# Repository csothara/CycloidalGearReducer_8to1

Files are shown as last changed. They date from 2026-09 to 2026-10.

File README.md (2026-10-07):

# CycloidalGearReducer_8to1
PID_noload2
result1
crosssection_analysis1

A personal project consisting in developing a cycloidal 8 to 1 reducer compatible with a NEMA17 stepper motor with a D-shaft.
This follows directly my previous project of a robotic arm articulated by servo motors after noting the flaws, design and servos limitations (extreme lateral play and backlash, bad repeatability etc).

Steppers can't generate a high torque, at least not in this context of building a robotic arm, so I need some gear reduction system to multiply the initial torque of 0.4Nm while being compact, having no backlash, high precision and being shock resistant.
I therefore chose the cycloidal type of reducers with a 8 to 1 reduction ratio, which, if well-designed enough, satisfies all my requirements and would give a torque of 3.2Nm (probably less because of friction...).
I also have to track the orientation of the output shaft with a magnetic encoder (AS5600) and communicate this angle to a PID closed loop control. 

In this project, I learned how to use Autodesk Fusion CAD because I don't want to use Blender (which I used to build the servo robot arm)

crosssection_analysis1

crosssection_analysis2

encoder

green is the input, blue is the stator, yellow is the gears, red is the output shaft, white rectangle is the magnet, solid dark green hanging is the encoder

Sources of materials that helped me a lot:
www.youtube.com/watch?v=dv2URKU5YNU //most useful video for me for understanding cycloidal reducers
www.youtube.com/watch?v=stGwlJ-GMCY
youtu.be/OsS9-FzKN6s?si=D96ZwXOTy2uzee3U
www.youtube.com/watch?v=VbAhkESCRFM //what taught me almost everything i needed for using Fusion CAD
youtu.be/jQ6LQBFZXmU?si=3ZcaHU4sGydaDMxd

Parts list:
26x 693ZZ Bearing                 www.amazon.fr/dp/B0FP4ZW9JP
2x 6702-2RS Bearing               www.amazon.fr/dp/B0GL6KSBSH
2x 6807-2RS                       www.amazon.fr/dp/B09HX12WTC
M3 Screws and Nuts                www.amazon.fr/dp/B0B3MGZ7T2 www.amazon.fr/dp/B0DPWZ53X4
AS5600 Magnetic Encoder           fr.aliexpress.com/item/1005009026945907.html
ESP32-S3 Microcontroller          fr.aliexpress.com/item/1005008845049090.html
TMC2209 V2.0 Stepper Motor Driver fr.aliexpress.com/item/1005010646278731.html
100µF Capacitor
some wires

The most difficult part for me in this project was to think about a step by step assembly process while making it compact and making every parts fit snuggly which led me to do a lot of iterations in certain models, even order an urgent express delivery for new parts, for example I realized very late that I needed much bigger bearings 6807-2RS because I did not think about needing a bigger output shaft with enough space for multiple screws to bear load, this adjustment rendered my gearbox to be too thick for my 20mm M3 screws which led to another express delivery of longer M3 screws, caliper broke etc

My experience of 3D modelling on Blender I gathered from the first lockdown translated really well to Fusion. The parametric curve maths logic of FUsion made it so much easier for me to keep track of all the dimensions otherwise impossible or very frustrating on Blender which uses a polygon mesh logic. This project took me 4 weeks to develop which would have taken months on Blender (the servo robot arm took me over 6 months).

Testing and assembly guide soon

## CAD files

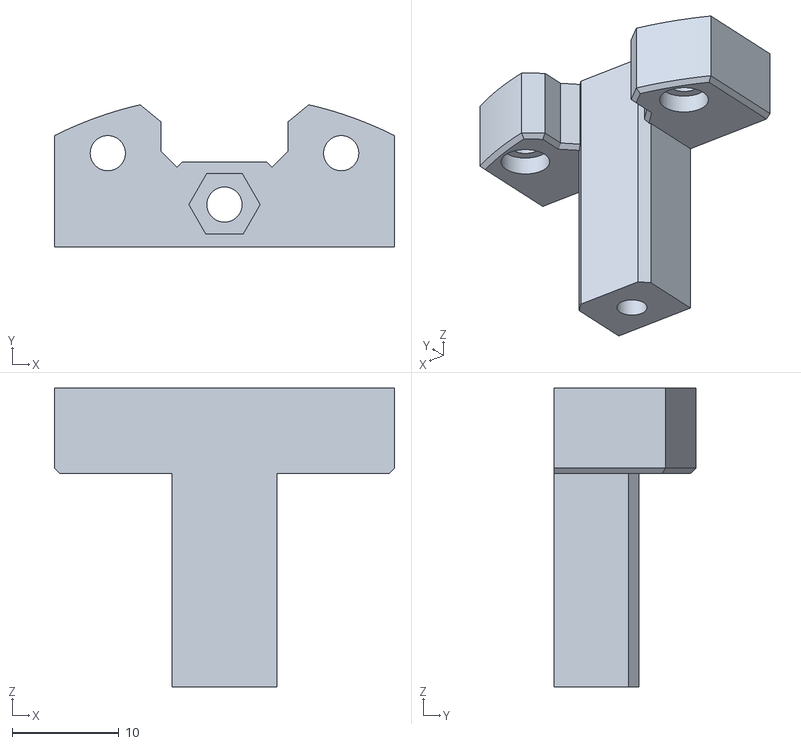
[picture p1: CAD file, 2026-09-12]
STEPPERMOUNT2_test_1.stl
31.9 x 13.4 x 28.0

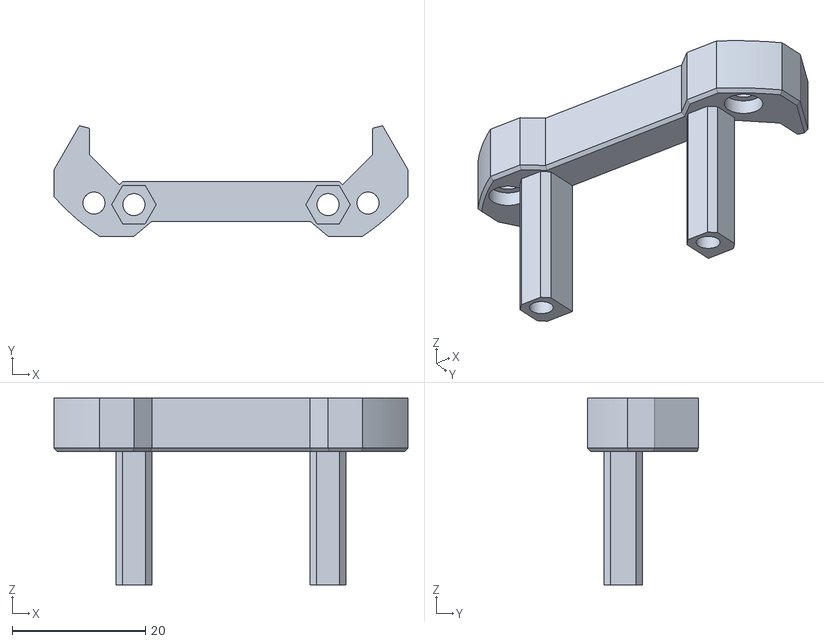
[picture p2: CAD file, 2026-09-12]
STEPPERMOUNT1_test_1.stl
53.1 x 16.6 x 28.0

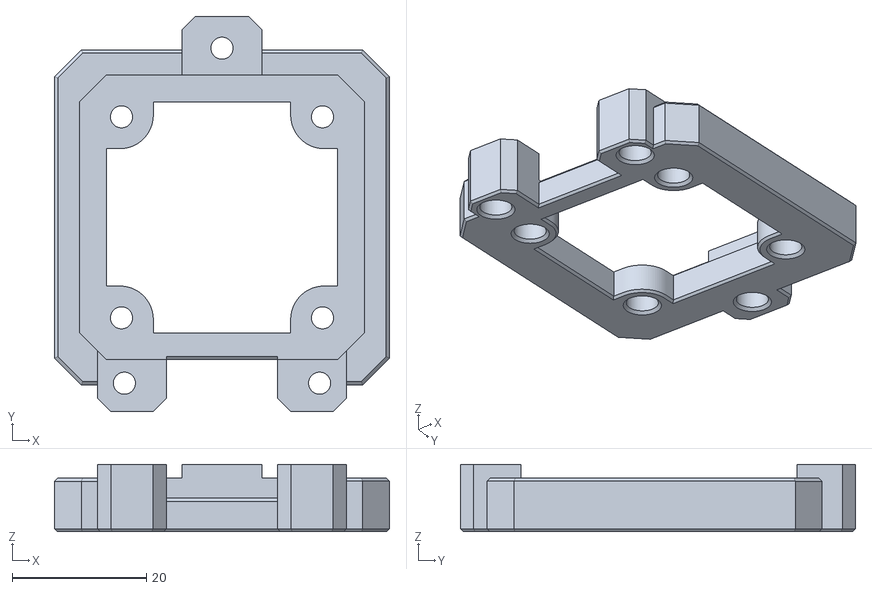
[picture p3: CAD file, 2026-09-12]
STEPPERMOUNT3_test_1.stl
50.0 x 59.0 x 10.0

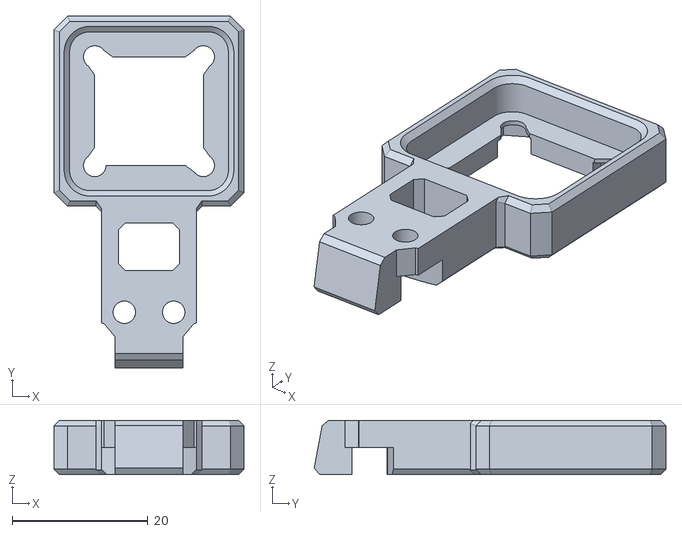
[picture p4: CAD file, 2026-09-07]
ENCODERHOLDER_test_2.stl
28.0 x 51.8 x 8.00

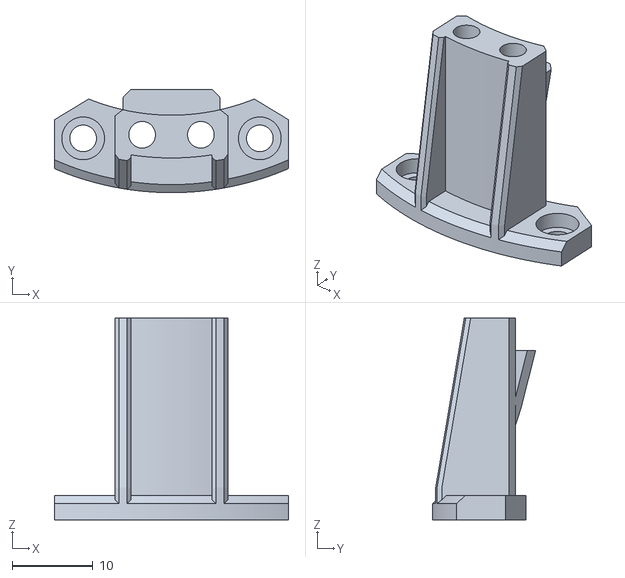
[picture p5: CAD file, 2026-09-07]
ENCODERBRIDGE_test_2.stl
29.0 x 12.8 x 25.0

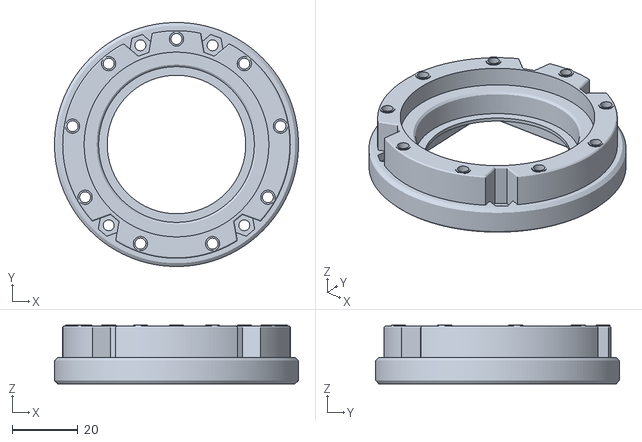
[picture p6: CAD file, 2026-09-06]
FIXEDFRAME_LOW_test_2.stl
74.0 x 74.0 x 17.8

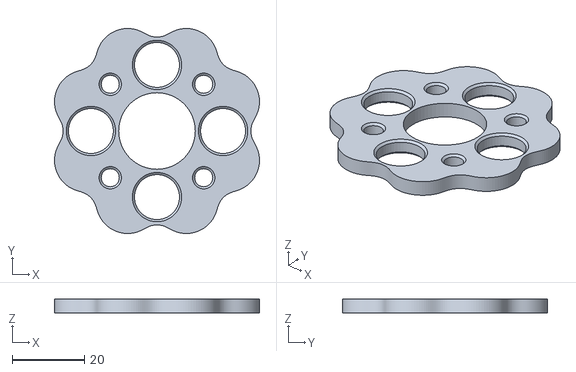
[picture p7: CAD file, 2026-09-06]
CYCGEAR1_test_1.stl
56.8 x 56.8 x 4.00

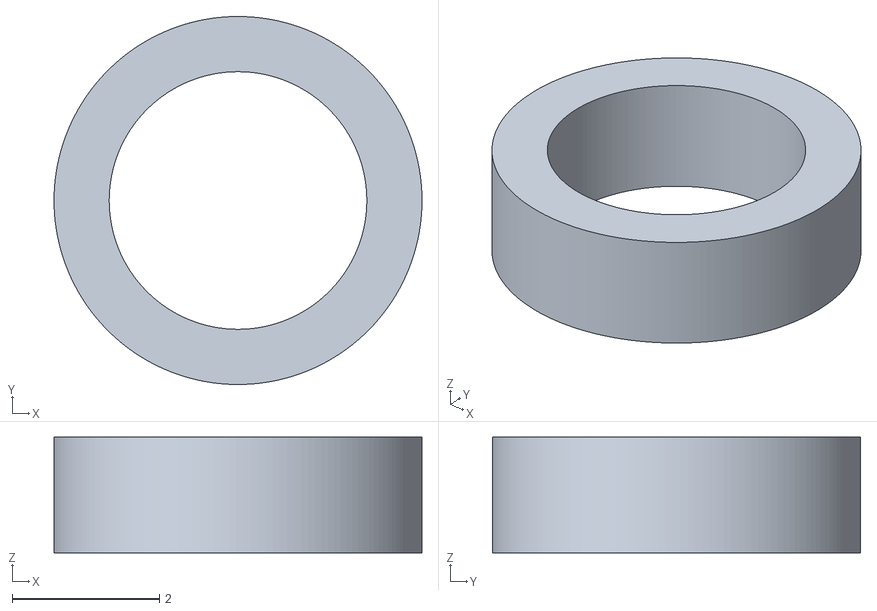
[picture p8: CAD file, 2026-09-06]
1mm575_SPACER.stl
5.00 x 5.00 x 1.58

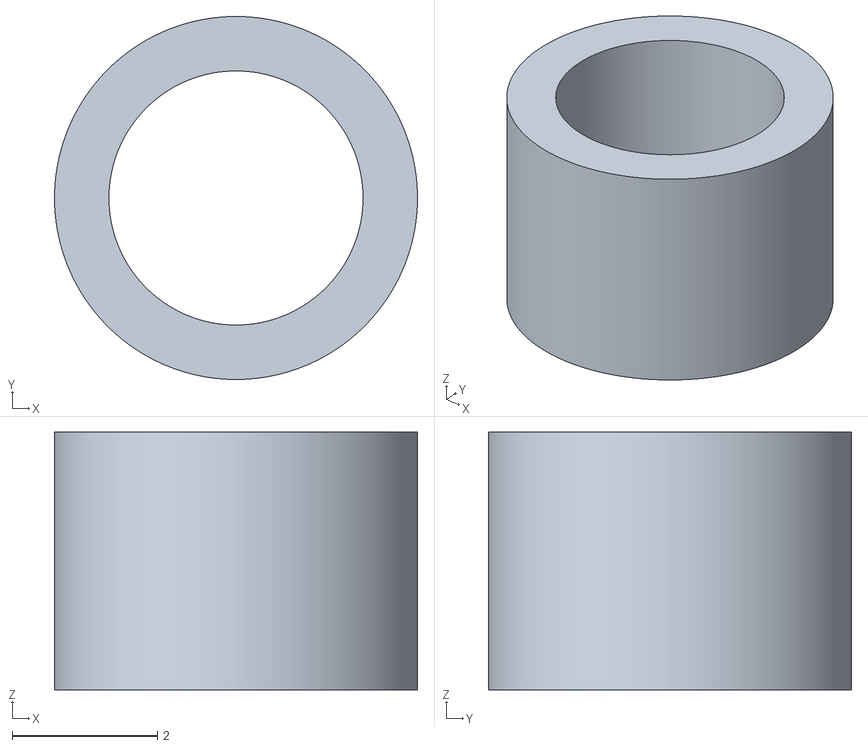
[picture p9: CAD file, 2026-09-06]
3mm55_SPACER.stl
5.00 x 5.00 x 3.55

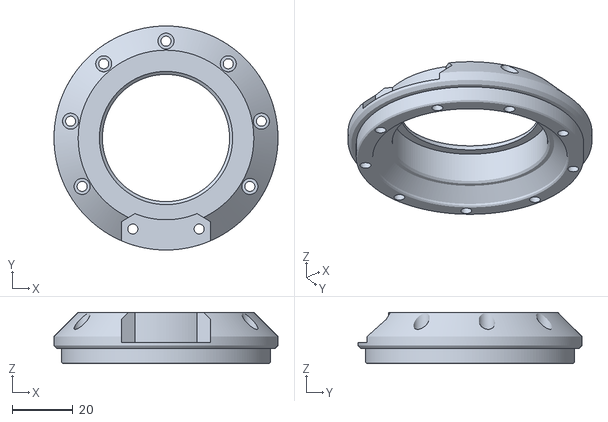
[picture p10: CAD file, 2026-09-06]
FIXEDFRAME_UP_test_2.stl
74.0 x 74.0 x 17.0

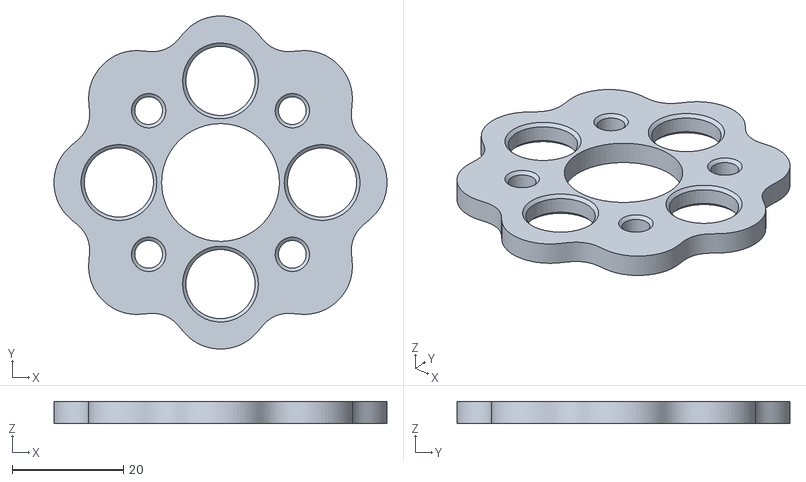
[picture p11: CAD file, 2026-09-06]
CYCGEAR2_test_1.stl
60.0 x 60.0 x 4.00

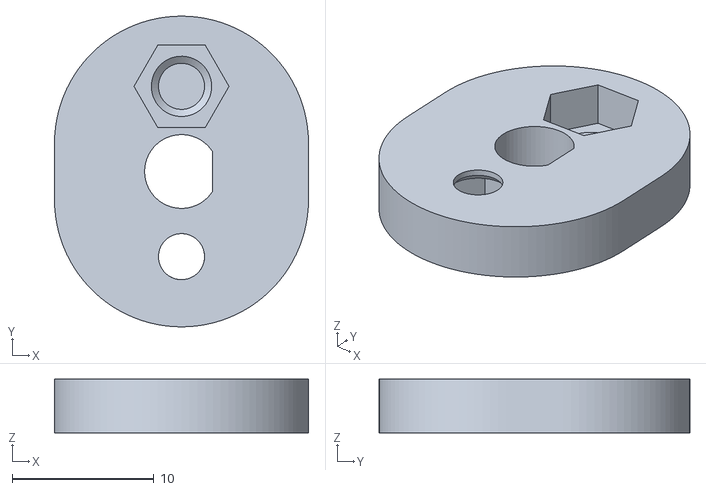
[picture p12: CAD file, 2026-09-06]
INPUTSHAFT_MID_test_3.stl
17.9 x 21.9 x 3.80

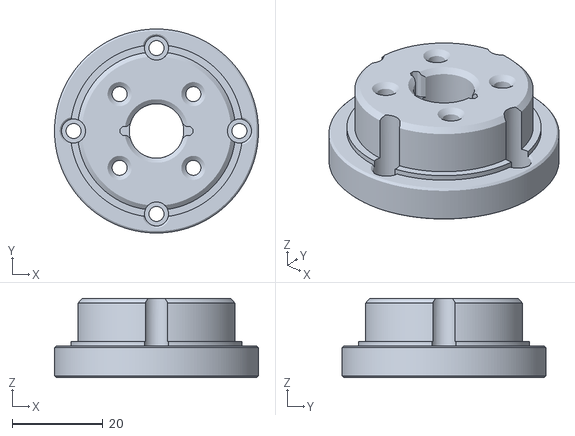
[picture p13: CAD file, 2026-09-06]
OUTPUTSHAFT_UP_test_5.stl
45.0 x 45.0 x 17.5

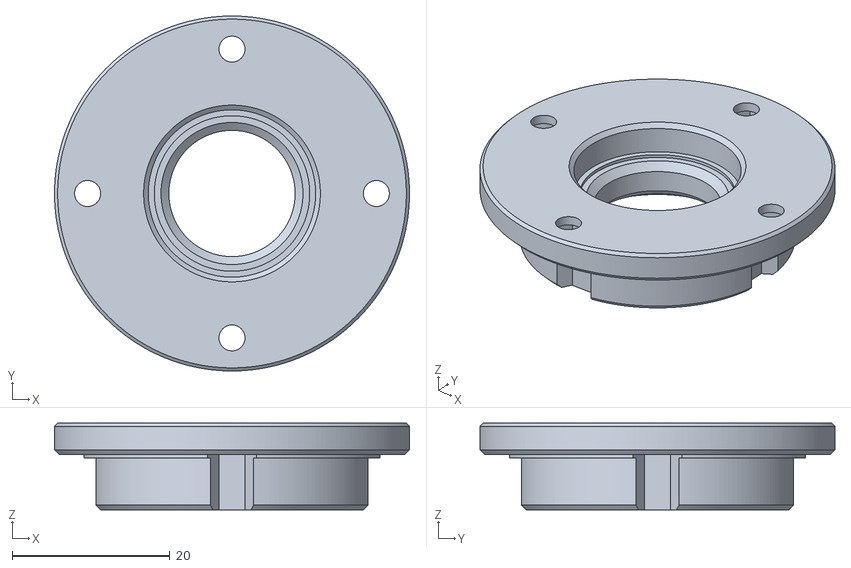
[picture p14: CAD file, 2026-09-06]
OUTPUTSHAFT_LOW_test_3.stl
45.0 x 45.0 x 11.0

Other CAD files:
INPUTSHAFT_UPnLOW_test_8.stl

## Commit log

2026-09-06 README
    Expanded project description to include details about the design choices and requirements for the cycloidal gear reducer.
2026-09-06 README
    Added project insights, sources, parts list, and assembly challenges.
2026-09-06 README
    Updated README to include PID control in the description and added a note about upcoming testing.
